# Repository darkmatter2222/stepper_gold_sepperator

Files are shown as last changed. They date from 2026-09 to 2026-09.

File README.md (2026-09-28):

# Stepper gold separator

PlatformIO / Arduino C++ firmware for the **ESP8266 NodeMCU ESP-12E shown in the hardware photo**, an assumed A4988 STEP/DIR carrier, one momentary button, and a switched 12 V Kamoer water pump. This is not an ESP32 build. It repeatedly rocks the bowl, pauses to settle, performs a ramped forward spin, pauses, and repeats until stopped.

**Starts stopped every time.** No unexpected motion after reset, firmware upload or power restoration. This firmware implements experimental motion, not proven gold recovery. The previous 64 mm bowl design does not establish an optimal speed. HIGH is a relative preset name, not a validated operating limit.

## Project files and revision selection

**For the current small prototype, use the v2 kit with the revised P01 cable-clearance base, P05 M3 hub and P08 brass-inlet lid.** Do not print the original P01/P05/P08 from the v2 snapshot for the current build. The original large v1 is preserved for reference.

| Folder or file | Contents / purpose |
|---|---|
| [Mechanical index](mechanical/README.md) | Current print list, quantities, revision precedence and archive map |
| [v2 kit](mechanical/gold_poc_v2/) | All nine original STL parts, individual STEP solids, assembly STEP, CAD generators, calculations, validation and rendered views |
| [Reinforced cable-clearance base](mechanical/base_cable_revision/) | Current P01 replacement; straight diagonal posts; existing P02 retained with four new drilled holes, wider posts and flared feet |
| [Hardware dimensions and assumptions](docs/HARDWARE.md) | Motor, pump, tubing, bearing, fastener and electronics reference; measured values separated from assumptions |
| [M3 drive hub](mechanical/hub_m3_revision/) | Current replacement P05, editable source, section and reviewed views |
| [Brass-inlet lid](mechanical/lid_water/) | Current replacement P08, editable source, section and reviewed views |
| [Illustrated assembly PDF](docs/guides/Central_Trap_Gold_POC_v2_Assembly.pdf) | Existing 18-page build guide; apply the hub/lid updates listed below |
| [Guide index and amendments](docs/guides/README.md) | Which guide applies and what has changed since its publication |
| [Original v1](mechanical/archive/gold_poc_v1/) | Superseded 128 mm bowl design and its source/checks |
| [Original ZIP deliveries](releases/original_packages/) | Unmodified v1 kit, v2 kit and M3 hub delivery packages |
| [Artifact manifest](docs/ARTIFACT_MANIFEST.json) | Byte sizes and SHA-256 checksums of preserved CAD, guides, source and review artifacts |
| [Wiring](docs/WIRING.md) / [pump](docs/PUMP.md) | Electrical connections, switching components and flow calibration |
| [Operating guide](docs/OPERATION.md) | Fill targets, staged feeding, size classification, capacity calculations and recovery tests |
| [Sources](docs/SOURCES.md) / [validation](docs/VALIDATION.md) | Research references, assumptions, checks and remaining physical tests |
| `src/`, `include/`, `test/`, `platformio.ini` | C++ firmware, settings, host tests and pinned PlatformIO environments |

The original assembly STEP and PDF show the original v2 base, hub and lid. The current replacement STEP files use assembly coordinates and can replace those parts in CAD. There is not yet a regenerated combined assembly STEP/PDF showing all three replacements. Their illustrated instructions take precedence for P01, P05 and P08.

## Mechanical design and hardware

This proof of concept has a **64 mm bowl**, reduced from the first version's 128 mm bowl. The original v2 assembled envelope is approximately **86 × 103 × 104 mm**, including the drain. The revised lid adds its collar above that height: its top is at assembly Z=120 mm, with a suggested 35 mm brass tube reaching approximately Z=137 mm, excluding flexible hose. Do not scale the STLs; motor, shaft, bearings and fasteners retain their real dimensions.

| Item | Current specification / qualification |
|---|---|
| Motor | Moons C17HD40-102-01N as reported; 5 mm shaft with a D-flat. Exact phase-current rating remains unverified |
| Motor envelope used in CAD | 42 mm square × 40 mm body, 31 mm mounting square, 22 mm pilot, shaft projection assumed about 18–26 mm |
| Shaft support | Separate 5 × 10 × 4 mm thrust bearing; motor supplies radial support |
| General assembly | M4 screws and heat-set inserts; v2 insert assumption approximately 6 mm OD × 6 mm long, nominal 5.6 mm pilot |
| Motor mounting | M3 threads in the motor; use the PDF's fastener schedule and confirm actual engagement |
| Revised P05 hub | One approximately 4.5 mm OD × 4 mm long M3 insert and M3 × 10 mm retaining screw against shaft flat; existing three M4 × 8 mm bowl attachments |
| Revised P08 lid | One matching-size M3 insert and M3 × 8 mm tube-retaining screw; original four M4 lid mounts retained |
| Brass inlet | 4 mm OD / 3 mm ID; start with 35 mm cut length; deburr both ends |
| Tube support | 4.2 mm socket, 18 mm engagement, 3.2 mm outlet below a positive seating shoulder |
| Feed opening | 26 mm diameter, retained in the revised lid |
| Pump | Kamoer NKP-DC-S10B, label 12 V / 5 W; actual flow and startup current require measurement |

Print the P09 insert coupon first. The nominal M4 insert hole is not universal; match it to your actual inserts. The M3 revisions also depend on insert OD and length, not just the M3 thread designation. PETG and robust perimeters are the starting print recommendations. Follow each part's orientation and support instructions. Closed STL geometry does not guarantee a watertight print; test wet parts separately.

The bowl has a blind central sump and smooth entrance; P07 is an optional recessed insert. The catcher uses a sloped floor and flush drain invert. A raised central shaft opening and splash labyrinth reduce splashing but are not a submerged rotary seal. Keep the drain open and capture all discharge. The inlet is off center, 22 mm from the axis, so it does not inject directly into the concentrate sump.

## Brass-tube lid and water pump

Print the [replacement lid STL](mechanical/lid_water/P08_lid_brass_4mm.stl), then follow the [illustrated assembly guide](mechanical/lid_water/README.md) and [12 V pump guide](docs/PUMP.md). The supported 4 mm brass tube seats on a shoulder so it cannot fall into the bowl.

## Wire first

See **[the wiring guide](docs/WIRING.md)** and **[the wiring diagram](docs/wiring.svg)**. The red carrier resembles an A4988, but its chip is hidden by the heatsink. Verify the driver model and printed terminal labels before powering it. A DRV8825 or another carrier may have different power pins and microstep settings.

Logical wiring diagram

| Signal | NodeMCU label | GPIO | A4988 / connection |
|---|---|---:|---|
| Step | D5 | 14 | STEP |
| Direction | D6 | 12 | DIR |
| Enable | D7 | 13 | EN, plus external 10k pull-up to 3V3 |
| Button | D2 | 4 | Normally-open button to GND |
| Water pump | D1 | 5 | 4.7k to 2N3904 base → IRF9540N high-side switch; see pump guide |
| Logic supply | 3V3 | | VDD, MS1, MS2, MS3, RESET, SLEEP |
| Common reference | GND | | Driver logic GND and motor-supply negative |

Use one regulated **12 V DC supply**: a secure branch feeds driver VMOT and the pump, while an **L7805 TO-220 linear regulator** supplies **5 V to NodeMCU VIN**. The upper breadboard positive rail is 5 V; the lower positive rail is 12 V; both negative rails share GND. Keep motor/pump current off breadboard rails. **Verify the actual regulator marking/pinout and NodeMCU VIN first; never apply 12 V to VIN or 5 V to 3V3.** See the wiring guide for capacitors, heatsinking and staged voltage checks. Disconnect external VIN power before attaching USB. The OLED partly visible in the photo is not required or driven by this firmware; disconnect it for initial testing, especially if it uses D2.

## Build and upload in VS Code

1. Install the PlatformIO IDE extension and open this repository folder (the one containing `platformio.ini`).
2. Turn off 12 V and disconnect the external 5 V-to-VIN lead before attaching USB. Select `nodemcuv2`, then click **Build**, followed by **Upload**. Keep external VIN disconnected while using USB Serial Monitor; unplug USB before restoring regulator power.
3. Open **Serial Monitor**, 115200 baud. If autodetection picks the wrong port, add `upload_port = COM5` and `monitor_port = COM5` with your actual Windows port.
4. It boots in LOW, IDLE. With wiring/current limit checked, hold the button for 0.8 seconds to start.

CLI equivalents:

```sh
pio run -e nodemcuv2
pio run -e nodemcuv2 -t upload
pio device monitor -b 115200
pio test -e native
```

The board/framework choice matches your [ESP8266 seismometer configuration](https://github.com/darkmatter2222/ESP8266_MPU6050_Seismometer/blob/main/platformio.ini). No GitLab account or URL was supplied; the accessible GitHub project was used. The platform and AccelStepper dependency are pinned for repeatable builds.

## One-button operation

| Action | Result |
|---|---|
| Short press and release | 1 → 2 → 3 → 4 → 5 → 6 → 1 |
| Hold for 0.8 seconds while idle | Start selected preset |
| Hold for 0.8 seconds while running | Decelerate to stop, then disable motor coils |
| Hold button during boot | No start; release it before normal operation |

While running, a newly selected mode is **queued until the next complete rock/settle/spin/rest batch**. It never changes speed abruptly mid-motion. The onboard LED flashes 1–6 times per three seconds for the selected mode. Serial reports the selected and currently active mode separately at the next motion pause. The LED pattern indicates mode, not running status.

Serial commands: `1`–`6` select; `s` start; `x` controlled stop; `!` immediately disables the driver; `?` requests status. `p` primes water for 3 seconds while idle; `c` runs a 30-second calibration while idle; `w` toggles automatic water. No newline required. Immediate disable removes holding torque and the bowl can coast. The button is a software control, not a physical emergency disconnect.

## Six modes and doubled agitation (2026-09-27)

The operator reports the previous mode 3 gave the best visible concentration and mud removal, with some heavy-mineral loss. Modes 1–3 retain their speeds and angles; their rocking cycle counts are doubled. Modes 4–6 are progressively faster trials, with counts chosen to preserve about 10 seconds of agitation. This increases time spent agitating; it does not double frequency.

| Mode | Name | Angle | Rock speed ceiling °/s | Rock accel °/s² | Cycles | Simulated agitation | Spin RPM | Spin accel °/s² |
|---|---|---:|---:|---:|---:|---:|---:|---:|
| 1 | LOW | ±12° | 540 | 7200 | 36 | 7.87 s | 90 | 1800 |
| 2 | MEDIUM | ±16° | 810 | 14400 | 48 | 8.62 s | 135 | 2700 |
| 3 | HIGH | ±20° | 1080 | 21600 | 60 | 9.92 s | 180 | 3600 |
| 4 | TRIAL4 | ±20° | 1170 | 25350 | 65 | 9.93 s | 195 | 3900 |
| 5 | TRIAL5 | ±20° | 1260 | 29400 | 70 | 9.93 s | 210 | 4200 |
| 6 | TRIAL6 | ±20° | 1350 | 33750 | 75 | 9.92 s | 225 | 4500 |

All modes retain 3 seconds settling, 0.5 seconds requested spin plateau and 2 seconds post-spin rest. Rocking brakes to zero before reversing, with triangular velocity profiles. Simulated frequencies are 4.60/5.59/6.07/6.57/7.07/7.58 Hz. Times are real-library host simulation results, not measured motor motion. Doubling cycle count approximately doubles duration; the initial/final half strokes prevent an exact 2.000× ratio.

Mode 3 is the comparison baseline. Try its longer agitation before increasing spin; modes 4–6 are not established recovery improvements. Keep all tailings. At 225 RPM the calculated radial acceleration at the 29 mm working radius is 1.64 g; faster ejection can lose desired minerals as well as gangue.

Keep existing 200-full-step, 1/16 microstep wiring. The maximum requested rate is now 12000 pulses/s, the existing software budget (about 83 microseconds per pulse). Actual ESP8266 scheduling/loaded torque are unmeasured. If motion stalls, slips or buzzes, stop and verify tracking rather than assuming commanded speed is achieved.

**Feeding and fill:** [OPERATION.md](docs/OPERATION.md) explains the photo, particle-size effects and staged feeding. The central void is about 2.27 mL up to its slope entrance, but that is not usable concentrate capacity. Start cleanup trials at roughly 0.5 mL retained settled bed; explore up to 1 mL only with acceptable measured losses. No validated maximum fill exists at mode 3 or the faster modes. Do not add unmeasured scoops to a full pocket. The machine supports periodic concentrate cleanup, not indefinite accumulation.

At the end of each spin, the stopped location becomes the next local rocking center. There is no homing sensor and no need to return to the original absolute shaft angle. Coordinates reset only at rest to avoid position accumulation over hours. No random stages are enabled, so experiments can be repeated and compared.

## Water delivery, flow rates and calibration

The pump runs at **full regulated 12 V when ON**. Firmware uses slow timed bursts rather than high-frequency PWM. GPIO D1 controls the MOSFET, not pump power directly. Automatic water defaults to enabled after boot, but output remains OFF until rocking begins. There is no unexpected prime on startup.

| Preset | ON per interval | OFF per interval | Nominal duty within a long uninterrupted rocking window | Ideal average if continuous flow is Q mL/min |
|---|---:|---:|---:|---:|
| LOW | 0.50 s | 4.50 s | 10% | 0.10 × Q |
| MEDIUM | 0.75 s | 4.25 s | 15% | 0.15 × Q |
| HIGH / TRIAL4 / TRIAL5 / TRIAL6 | 1.00 s | 4.00 s | 20% | 0.20 × Q |

**These are timing ratios, not measured water flow rates.** Each rocking batch begins with an ON pulse; the batch can end partway through an interval. Water is OFF during centering, settling, spin, rest and stopping. Consequently, multiplying by 10/15/20% does not give the whole-machine average, and the actual cyclic average is not necessarily lower than those ratios because intervals restart. Short-burst startup, pump rollers, hose elasticity, lift and outlet restriction also affect delivery. The exact NKP-S10B tube configuration and a manufacturer flow curve for this unit have not been verified. We have not simulated or optimized this system's water flow.

For measured pump ON time `t_on` over complete elapsed time `T`, an ideal estimate is `Q_cycle ≈ Q_continuous × t_on / T`. Measuring actual collected volume over complete cycles is better.

1. Route the installed outlet to a graduated cup at the operating height. Prime the line with `p` (3 seconds) until it is full and bubble-free.
2. While idle, send `c` for a 30-second continuous pump run. If the cup contains **V mL**, the measured continuous estimate is **2 × V mL/min**. Repeat for consistency.
3. Run each preset for a measured number of minutes, collecting output across complete motion batches. **Actual average mL/min = collected mL ÷ elapsed minutes**. Record tube dimensions, lift, preset and edited timings with the result.
4. Confirm the assembled catcher's outlet clears inflow without a rising level. Start with an empty bowl, then water, then a very small prepared sample. No maximum drain throughput has been measured.
5. Edit `PUMP_SCHEDULE` and repeat if the bed dries out, material cannot wash away or the catcher accumulates water. More water can also carry fine gold away. Retain tailings.

For arithmetic illustration only, collecting 20 mL during a 30-second calibration means 40 mL/min continuous. The ideal long-window rates at 10/15/20% duty would be 4/6/8 mL/min, but these are **not this pump's measured ratings** and must not be used as actual separator setpoints.

| Measurement | Current status |
|---|---|
| Nameplate supply | 12 V DC |
| Nameplate power | 5 W |
| Current inferred from 5 W / 12 V | About 0.42 A; not measured running or stall current |
| Continuous installed flow | Not measured |
| All six modes: whole-cycle flow | Not measured |
| Maximum catcher drainage rate | Not measured |
| Recovery versus flow or feed size | Not measured |

The brass bore has cross-sectional area about 7.07 mm². If actual flow is `Q` mL/min, mean velocity in its 3 mm ID straight section is approximately `0.00236 × Q` m/s. This dimensional calculation is not a nozzle, pressure-drop, splash or particle-recovery simulation. Flow near the bowl depends on the free jet and liquid bed as well as the tube.

Use the [pump guide](docs/PUMP.md) for MOSFET wiring, flyback protection, supply sizing, terminal direction and siphon checks. Keep hoses strain-relieved. A stopped peristaltic pump is not assumed to be a certified shutoff valve.

## Complete controls and settings

| Serial command | Meaning |
|---|---|
| `1`–`6` | Select one of six presets; apply at next complete batch if already running |
| `s` | Start motion from idle; automatic water follows its phase schedule |
| `x` | Shut water off immediately, decelerate motor, disable coils once stopped |
| `!` | Shut water off and disable drive immediately; rotor can coast |
| `p` | 3-second prime while idle only |
| `c` | 30-second calibration while idle only |
| `w` | Toggle automatic-water enable; cancel current pump output |
| `?` | Print phase, selected/active mode and water state |

Manual prime/calibration requests during motion are ignored. Repeating a manual command does not extend an active dose. Starting motion cancels manual dispensing. A short button press changes the selected preset; it is not a stop command. A long press starts or requests controlled stop. Use a physical power disconnect when servicing.

`include/Config.h` contains motion profiles, pin numbers, motor steps, microstep count, pump ON/OFF times, prime/calibration duration, direction inversion and the experimental `PUMP_DURING_SPIN` option (default false). Durations are milliseconds unless the field says otherwise. All settings are compile-time; rebuild and upload after editing. Serial changes are not persisted after reset.

## Separation mechanics and research limits

The intended sequence is rocking to loosen/stratify the bed, a quiet settling interval, then a brief ramped forward spin to move some material outward. Gravity and the bowl slope can favor inward transport when grains can move. Rotation produces outward acceleration `a = omega² × radius`; it is not a guarantee that light material exits while all gold stays centered. Both grain size and density matter, and flakes can behave differently from spheres.

At the 29 mm working radius, 90/135/180/195/210/225 RPM correspond to approximately 0.263/0.591/1.050/1.233/1.430/1.641 g radial acceleration. These are analytical screening values, not a recovery model. See [capacity calculations](docs/CAPACITY_SCREENING.json) and [motion history](docs/MOTION.md).

The goal is a dense concentrate at the center. The pocket can fill with black sand and other heavies; it cannot guarantee pure gold or prevent every fine particle escaping. Clay must be dispersed to free trapped gold; wet screening alone may not do that. The present prototype has no automated feed conveyor or concentrate discharge. Automatic repeated motion is implemented; hours of unattended bucket-scale processing have not been established.

## Tuning and first run

Edit `include/Config.h` for pins, motor step count, microstep count, direction inversion and presets. Settings are compile-time and are not written repeatedly to flash. No Wi-Fi, cloud service or phone is needed. Water bursts are integrated into the rocking phase; see [pump wiring and calibration](docs/PUMP.md).

1. Verify motor coil pairs, driver identity, supply polarity and current limit as described in the wiring guide. The exact Moons motor's phase-current rating is not known from the photo.
2. Hand-turn the assembled bowl and check the new M3 hub screw and bearing clearance. Secure the cover and catch all overflow.
3. Start LOW with an empty bowl, then water only. Stop if it stalls, buzzes without moving, rubs, or gets excessively hot. Confirm direction; `INVERT_DIRECTION` reverses it.
4. Add a very small screened/dispersed sample. Keep all tailings and measure losses before increasing intensity. Start with measured small doses and the fill/cleanup procedure in OPERATION.md. Faster modes can increase losses.
5. Tune one parameter at a time. More spin pushes particles outward and can remove gold as well as sand. Clay, flakes and bed loading affect settling; these dwell times are not a guarantee that flour gold settles.

No encoder, stall detection, current measurement, temperature sensor or blocked-drain detection is provided by this hardware/software. A4988 does not report these conditions to this controller. Long unattended processing is not validated. The loop uses AccelStepper cooperatively with Wi-Fi disabled; verify actual timing under your hardware conditions before increasing pulse rates. Logging is deferred when the serial transmit buffer lacks space.

## Validation

Host tests cover boot-idle behavior, button bounce/long-press/boot-held behavior, millisecond rollover, queued mode transitions, every normal stop phase, immediate disable, spin-distance calculation, and coordinate resets over 1000 batches. The fake motor tests control logic; they do not establish physical pulse timing or recovery. GitHub Actions runs those tests and builds the ESP8266 firmware. See [sources and engineering notes](docs/SOURCES.md).

Pump tests cover burst timing across reversals, phase gating, preset timing, immediate cancellation, manual time limits, rollover and delayed-loop behavior. The original pump revision passed 15 host tests and built for `nodemcuv2` (RAM 28,844 bytes; flash 273,491 bytes). See [validation](docs/VALIDATION.md) for the current motion revision. Hardware flow and electrical startup behavior remain to be measured.

## P01 straight-post correction

The rejected angled-post version has been replaced with [straight vertical posts](mechanical/base_cable_revision/README.md), rotated to the diagonal positions. Posts are 12 mm nominal diameter with 16 mm flared feet. Unused bottom holes and cable-tie slots are removed. **Keep the existing P02 upper plate, but drill four new 4.5 mm holes using the included template.** No upper-plate reprint is needed; this is not a fit against the unchanged old hole pattern. Local reliefs clear the motor corners and existing upper bosses. See the revision instructions before printing or drilling.

The source, STL/STEP, template, drilled-deck reference STEP, assembly views and checks are committed together. Hardware dimensions and unresolved measurements are in [HARDWARE.md](docs/HARDWARE.md). Pump body dimensions remain unmeasured; no flow or physical strength guarantee is implied.

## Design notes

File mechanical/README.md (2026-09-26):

# Mechanical files and current print list

Use the compact **v2** kit with **all three** revisions below. The original snapshots and ZIPs are retained without rewriting their contents.

| Part | Qty | Current print file |
|---|---:|---|
| P01 base | 1 | [STL](base_cable_revision/P01_BASE_STRAIGHT_VERTICAL_R3.stl) |
| P02 motor deck | 1 | [STL](gold_poc_v2/STL/P02_motor_deck.stl) |
| P03 spacer | 4 | [STL](gold_poc_v2/STL/P03_spacer_x4.stl) |
| P04 catcher | 1 | [STL](gold_poc_v2/STL/P04_catcher.stl) |
| P05 drive hub, M3 revision | 1 | [STL](hub_m3_revision/P05_drive_hub_M3.stl) |
| P06 bowl | 1 | [STL](gold_poc_v2/STL/P06_bowl.stl) |
| P07 optional trap insert | 0 or 1 | [STL](gold_poc_v2/STL/P07_optional_trap_insert.stl) |
| P08 brass-inlet lid | 1 | [STL](lid_water/P08_lid_brass_4mm.stl) |
| P09 insert coupon | 1 initially | [STL](gold_poc_v2/STL/P09_insert_coupon.stl) |

All dimensions are millimeters. Do not scale. STEP files and editable Python generators accompany each revision. Hardware STEP envelopes in the kit are reference solids, not printable substitutes for motors/bearings.

Read the [assembly guide index](../docs/guides/README.md), [M3 hub instructions](hub_m3_revision/README.md) and [brass lid instructions](lid_water/README.md). The baseline kit's PDF and assembly STEP predate those three replacements. Its original base, hub and lid remain available only as revision history.

## Folder organization

- `gold_poc_v2/`: complete compact kit, original PDF, source, model files, review images and calculation/check records. The original relative layout is retained so source and assets remain together.
- `hub_m3_revision/`: current P05 and its validation/rendering source. Kept beside `gold_poc_v2` so original clearance-reference paths work.
- `lid_water/`: current P08 and its validation/rendering source. Pass `../gold_poc_v2/STEP` to the generator when running from this folder to include original-kit clearance checks.
- `archive/gold_poc_v1/`: superseded larger prototype. Do not mix its parts with v2.
- `../releases/original_packages/`: unmodified historical delivery ZIPs.

The files are preserved deliverables, not newly manufactured/tested hardware. Geometry checks describe the revision that generated them. Re-run appropriate checks after any edit. The v2 guide generator writes its PDF to its parent folder; avoid overwriting the preserved guide inadvertently.

The large intermediate mesh-render cache is preserved losslessly as `gold_poc_v2/assets/meshes.json.gz`. Run `gzip -dk assets/meshes.json.gz` from the v2 folder if a rendering script needs the JSON cache; the original generators can also recreate it.

## Straight-post base correction

Use [base_cable_revision](base_cable_revision/README.md) for P01. All post axes are vertical, at the diagonal positions. The printed P02 deck is retained but needs four new 4.5 mm holes using the supplied drill template. The previous angled supports are rejected and superseded. Bottom cable-tie/anchor holes have been removed. Read the complete instructions before printing.

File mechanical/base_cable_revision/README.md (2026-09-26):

# P01 straight-post base: corrected revision

**Download `P01_BASE_STRAIGHT_VERTICAL_R3.stl`.** Remove the previous angled model from your slicer before importing this file. Its posts run vertically, with no sideways displacement between their top and bottom axes. The earlier reused filename could make downloads difficult to distinguish.

[Base STL](P01_BASE_STRAIGHT_VERTICAL_R3.stl) · [Base STEP](P01_BASE_STRAIGHT_VERTICAL_R3.step) · [Drill-template STL](P02_drill_template.stl)

**This replaces the rejected angled/swirl-post design. All four post axes are now straight and vertical.** The lower and upper ends occupy the same diagonal positions, 45° from the original post layout. The base has no unused anchor holes or cable-tie slots.

**Keep your printed P02 upper plate, but drill four new 4.5 mm clearance holes in it.** The old upper screw holes are at the cardinal positions. They cannot fasten straight diagonal posts. This is not a drop-in replacement against an unmodified P02. If you do not want to drill it, do not print this revision on the assumption that its holes already match.

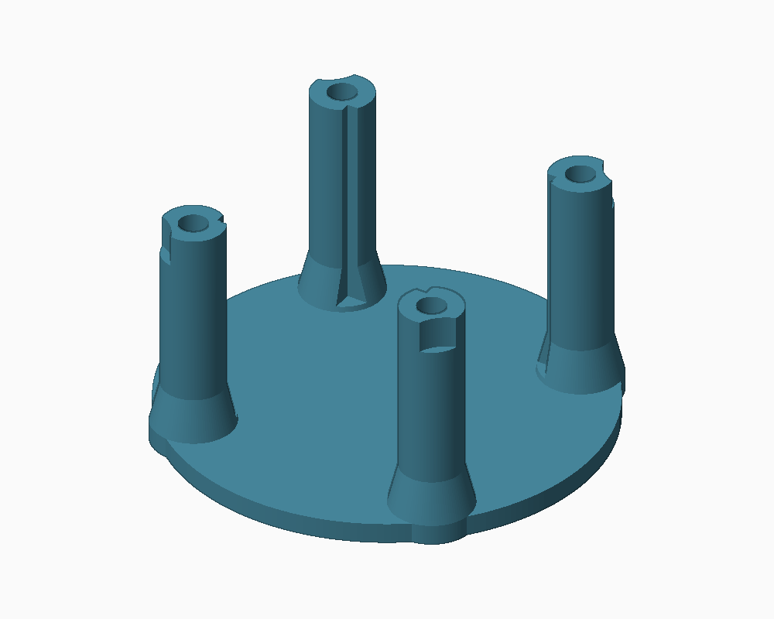
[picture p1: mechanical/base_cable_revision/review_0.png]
Straight-post base


## Dimensions and changes

| Feature | Corrected geometry |
|---|---|
| Main plate | 84 mm diameter, 4 mm thick |
| Post axes | Radius 35.5 mm, angles 45/135/225/315°; vertical throughout |
| Post section | 12 mm nominal diameter; original posts were 9 mm |
| Feet | 16 mm nominal diameter, taper to 12 mm over Z=4–12 |
| Top height | Z=46 mm, same height as original base |
| M4 insert pilot | 5.6 mm diameter, 6.5 mm depth |
| New upper plate holes | 4.5 mm diameter at X/Y = ±25.1023 mm (all four combinations) |
| Motor clearance | 44 × 44 mm internal relief around assumed 42 × 42 mm motor |
| Existing deck bosses | Local curved relief at post tops, radius 7.3 mm about the original R47 boss centers |
| Extra bottom holes | Removed |

The inward post/foot faces are locally relieved to clear the motor corners. A small curved relief at each post top clears the existing upper plate's underside mounting boss. These are clearance cuts in straight vertical posts, not angled arms. Feet have rounded plan outlines; no supports should be required for the base in its supplied flat orientation, but inspect your slicer preview.

## What the old holes were

The original P01 had two rectangular 3 × 7 mm slots for cable ties/strain relief. No printed part was intended to fit them. Its four round bottom holes were optional base anchoring holes, not required separator assembly interfaces. Both sets are removed from this corrected base. The required M4 insert pockets remain at the post tops.

## Print and fit

1. Print the base flat at 100% in millimeters. PETG, approximately 0.2 mm layers and at least five perimeters are starting settings. Review infill and layer bonding around the feet. No physical strength test has been performed.
2. Fit four M4 heat-set inserts, assuming approximately 6 mm OD × 6 mm long, after checking your actual inserts against the original coupon. Let them cool; inspect the locally relieved post tops for damage.
3. Disconnect power and remove the motor and upper components from P02 before drilling. Keep debris out of bearings, motor and electronics.
4. Print the 3 mm thick drill template. Its four cardinal holes at radius 36 mm align with the old base screw holes. Locate it on the **top face** of P02 using two opposite old holes and temporary M4 screws; clamp the plate flat on scrap wood. The template's center opening clears the central pedestal. Do not confuse its locating holes with the four new diagonal holes.
5. Mark the four new diagonal centers through the template. Remove the template, check spacing (50.2046 mm square), then drill 4.5 mm through P02's 4 mm plate only. Deburr. The template is a positioning aid, not a hardened drill bushing; do not melt it with a powered bit. Existing outer bosses/catcher holes must remain untouched.
6. Reassemble using the original four M4 × 10 mm deck-to-base screws in the **new** holes. Confirm insert engagement and that the screws do not bottom out. The four old deck clearance holes are now unused; leaving them open does not change the dry deck's function.
7. Connect the harness through the open face between posts and confirm plug/latch access and cable bend clearance. Hand-turn the rotor, then test empty at LOW. Firmware is unchanged.

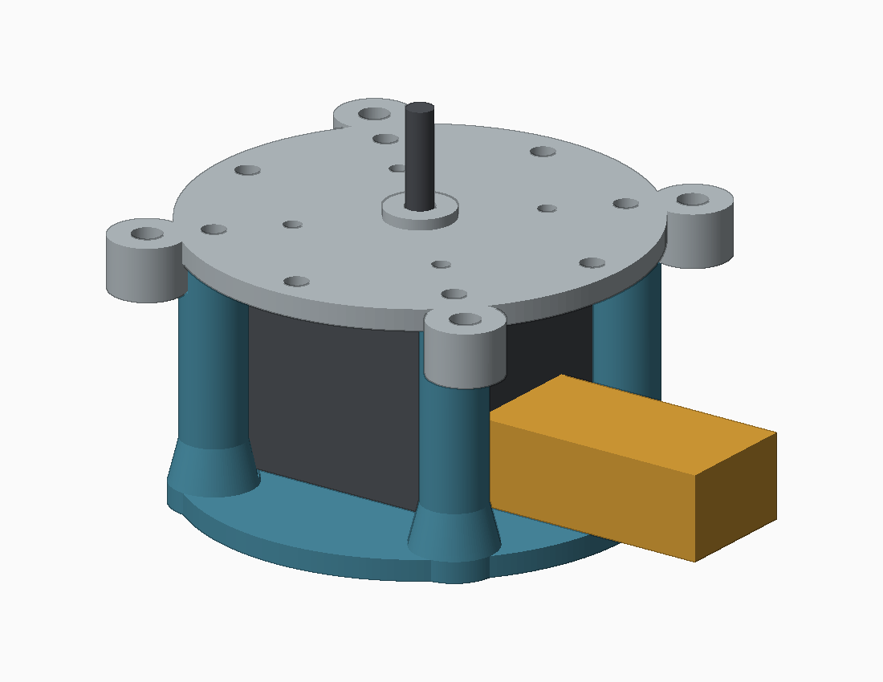
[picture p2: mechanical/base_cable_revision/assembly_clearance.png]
Base with motor, drilled deck and connector allowance


## Checks and reference files

CAD checks verify one valid base solid, closed/oriented STL, and no volumetric intersection with the motor envelope, drilled deck or 24 mm-wide × 16 mm-high assumed connector corridors (Z=6–22) on any of four faces. Connector dimensions remain unmeasured. Review images show the actual exported STL. `checks.json` records results.

`P02_drilled_reference.step` shows the **existing plate with four new holes**, for inspection, not a request to reprint it. `base_motor_deck_reference.step` includes the corrected base, reference motor and drilled deck. `P02_drill_template.step` is editable template geometry. The main kit's original PDF and assembly STEP remain historical snapshots; these instructions supersede their base attachment step.

Run `python build_base.py` with CadQuery 2.7, NumPy, SciPy and Pillow to regenerate. Original references come from `../gold_poc_v2/STEP`. Print tolerances, actual cable fit and structural performance require physical verification.

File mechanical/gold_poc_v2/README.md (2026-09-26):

# Central Trap v2 - compact experimental gold separator

Start with `Central_Trap_Gold_POC_v2_Assembly.pdf`. It contains the 18-page illustrated build sequence, hardware list, fit checks, printing notes, water-path sections, commissioning plan and research limitations.

## Size and changes

- Bowl diameter: 64 mm (v1: 128 mm).
- Assembled envelope: approximately 86 x 103 x 104 mm, including drain.
- Motor, M4 fasteners, inserts and bearing remain full-size. Do not halve these STLs in the slicer.
- One-piece wet bowl with smooth central sump entrance and blind dry mounting holes.
- Catcher floor slopes 3% to a flat-bottomed drain bore. Its invert follows the floor; no raised drain sill is designed in.
- Rounded mounting bosses replace square tabs. Recessed center insert is optional and gravity-seated, not a one-way trap.
- Direct 5 mm motor-shaft drive with a separate 5 x 10 x 4 mm thrust bearing. The motor still provides radial support.

## Before printing

The exact Moons C17HD40-102-0 1N specification was not verified. Check the assumptions: 42 mm square, 40 mm body, 31 mm mounting square, 22 mm pilot no more than 2 mm high, 5 mm shaft with approximately 18-26 mm projection from the motor mounting face. A longer body, different pilot or different shaft projection needs a CAD revision.

Print P09 first. Nominal insert bores are 5.6 mm, intended for roughly 6 mm OD x 6 mm long M4 inserts. Your insert manufacturer's bore recommendation takes precedence. The coupon contains 5.2, 5.4, 5.6, 5.8 and 6.0 mm bores. M3 screws are required only for the motor's own mounting threads; assembly hardware is M4.

Print one of each STL except P03 (four copies). P07 is optional. STLs are already print-oriented. P02 needs support around the bearing pedestal; P04 needs support under its spout/body and projecting upper bosses; P06 needs external support under the flare and skirt. Keep supports out of the wet working surface. Details are in the PDF.

## Package contents

- `STL/`: nine separate print files, millimeters.
- `STEP/`: individual solids in assembly coordinates plus simplified hardware reference geometry. Hardware models are not printable replacements for bearings or motors.
- `assembly.step`: assembled layout without screws, inserts, tubes or optional trap insert.
- `assets/review_*.png`: actual STL meshes, three viewpoints per part.
- `assets/section_*.png`: CAD sections through bowl and catcher.
- `assets/step_*.png`: exploded assembly illustrations.
- `geometry_checks.json`: solid validity, dimensions and interference checks.
- `mesh_checks.json`: STL closed-edge/orientation/positive-volume results.
- `mechanics_screening.json`: simple analytical calculations, not CFD.
- Python source for geometry, rendering, checks and the PDF.

## Verification and limits

All nine meshes were visually reviewed from three directions. CAD solids are valid; STL edges form closed oriented meshes with positive volume. Modeled printed parts, motor and bearing envelopes have no detected intersections. Rotor clearance was checked at 15-degree intervals. Fasteners are specified but not included in the interference model. Physical balance, torque margin, stepper temperature, print tolerances and water leakage are not validated by CAD.

There is NO CFD, multiphase particle simulation or measured gold recovery. The 20.2-degree slope is an experimental choice, not an optimized or proven geometry. Static friction, grain shape, mud rheology, surface roughness, gold size and water flow can defeat inward transport. Clay must be dispersed; screening alone does not free clay-bound gold. A deep pocket can fill with non-gold heavies. No guaranteed capture or unattended continuous-feed capability is claimed.

Mesh watertightness means closed geometry, not a leakproof FDM print. Leak-test wet parts separately. The catcher has an intentional raised central shaft opening and rotating splash labyrinth; it is not a submerged shaft seal. A blocked drain can wet the motor. The cover is a splash cover, not a pressure seal.

Start with water only, then very small screened samples. Retain and inspect all tailings. Follow the guide before trying spin/ejection pulses. To recover concentrate, stop and isolate power, remove the cover, use a small pipette/snuffer, and rinse the sump into a separate pan; remove the rotor for complete cleaning. Do not remove or collect from the rotating assembly.

## Rebuilding

Environment used: Python 3, CadQuery 2.7.0, NumPy 2.3.5, SciPy 1.17.0, Pillow 12.3.0, ReportLab 4.4.9. PDF generation also expects DejaVu Sans fonts in the standard Linux font path.

Run in order:

```bash
python build_v2.py
python checks_v2.py
python render_v2.py
python make_guide.py
```

Geometry dimensions are in `build_v2.py`; `INS` controls insert-bore diameter. Motor changes require checking the full stack and clearances rather than scaling the assembly. The PDF generator writes its PDF in the parent directory. Scripts overwrite generated artifacts; preserve a copy before modification.

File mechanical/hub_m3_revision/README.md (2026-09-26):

# P05 drive hub - single M3 insert revision

This part replaces only P05 in Central Trap v2 (64 mm bowl). All other printed parts remain unchanged. The previous guide's two M4 hub inserts and two opposed set screws are superseded by ONE M3 insert and ONE M3 screw.

## Hardware and pocket

- One M3 heat-set insert, assumed approximately 4.5 mm outside diameter x 4 mm long.
- One M3 x 10 mm socket-head screw with a flat end, bearing on the motor shaft's D-flat. A blunt flat-point grub screw may also be used if its length/reach is checked.
- Nominal insert pilot: 4.0 mm diameter, 4.5 mm pocket depth, 0.3 mm entry chamfer. Insert flush with the flat outside boss face. The final 3.2 mm passage leads to the shaft bore.
- M3 refers to the thread, not the insert's outside diameter. Verify your actual insert dimensions and recommended pilot before printing; do not force a larger insert into this pocket.

## What changed

A solid round radial boss supports the insert all the way around and provides a flat face for installation. The screw is lower than in the previous design so a straight hex key can reach it through the gap below the catcher. The second radial hole is gone.

Preserved interfaces: 36 mm flange, 10 mm total hub height, 5.1 mm motor-shaft bore, 29 mm bolt circle with three 4.5 mm holes, and the 10 mm diameter bearing nose. The shaft bore remains round to accommodate an unmeasured D-flat; the single screw presses the shaft against the opposite bore wall.

## Assembly

1. Print the STL in its supplied orientation, broad flange on the bed. Use the prior kit's PETG and perimeter settings. Keep the horizontal insert pocket clean; check the slicer for any local support needed and remove it completely.
2. Before attaching the bowl, heat-set the M3 insert from the outside of the boss. Align it with the hole and seat it flush. Let the part cool completely. Do not melt the insert through the pocket shoulder or distort the shaft bore.
3. Check that the screw threads smoothly through the insert and can reach into the shaft bore. Back it out to clear the bore.
4. Attach the hub to the bowl using the existing three M4 x 8 screws.
5. Lower the rotor onto the 5 mm shaft and thrust bearing as before. Align the shaft D-flat with the new M3 screw.
6. Tighten the M3 screw gently against the flat through the under-catcher access gap. Avoid bearing preload and excessive torque on the plastic insert boss.
7. Hand-turn the rotor through a full revolution. Check screw-head clearance, bearing freedom and any visible wobble before powering it.

The nominal M3 x 10 screw is modeled with its tip at a shaft flat 2 mm from the shaft center. Actual flat depth and screw end geometry vary. Confirm it clamps the shaft before any other surface bottoms out. A socket screw head may sit slightly proud of the boss; that is intentional and included in the clearance check.

## Included files and validation

- P05_drive_hub_M3.stl: millimeters, ready to slice; do not scale.
- P05_drive_hub_M3.step: original assembly coordinates, for CAD editing.
- build_hub.py: editable source. INSERT_BORE and INSERT_DEPTH control the pocket.
- review_0.png through review_3.png: views rendered from the actual exported STL.
- assembled_hub.png: illustration with nominal insert and screw envelopes.
- section.png: section showing the insert pocket and shaft passage.
- checks.json: mesh and clearance results.

The STL is checked for closed, consistently oriented edges and positive volume. CAD checks include the nominal screw head at 15-degree rotational increments against the existing catcher, deck and cover, plus a straight hex-key access envelope. These are geometry checks, not a physical print or clamp-strength test. One screw and insert introduce some imbalance; no high-speed balance or torque rating is claimed.

The source uses CadQuery, NumPy, SciPy, Pillow and the included render_support.py. Full assembly-clearance verification also uses the previous kit's STEP references. Keep this folder alongside the previous kit folder named gold_poc_v2 to re-run those checks. Without those reference files, only the hub and mesh checks run.

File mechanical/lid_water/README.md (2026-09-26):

# P08 replacement lid — 4 mm brass water inlet

[Print STL](P08_lid_brass_4mm.stl) · [Editable STEP](P08_lid_brass_4mm.step)

Only the lid changes. Original 86 mm body, 26 mm material-feed opening and four M4 mounting positions are retained. The old spare water hole is closed. The supported inlet is 22 mm off center; it does not aim directly into the central concentrate trap.

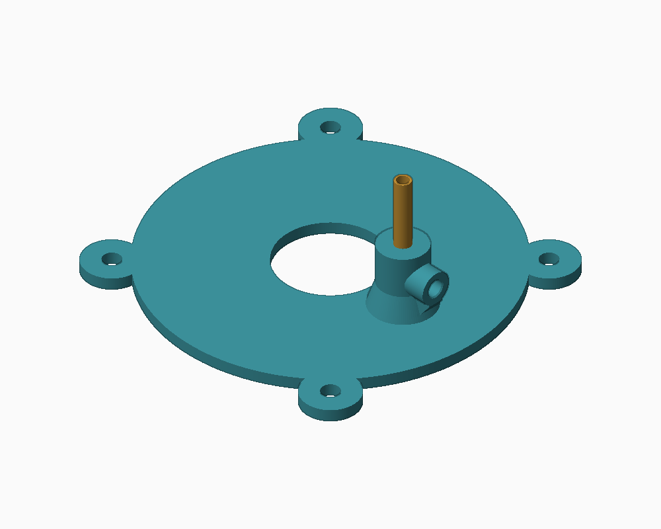
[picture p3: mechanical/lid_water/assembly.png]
Assembled lid


## 1. Print the lid

Print the STL as supplied, flat underside on the bed, without scaling. PETG, 0.2 mm layers and at least five perimeters are a practical starting point. Overall height is 19 mm. Inspect the horizontal insert bore for bridge sag; use localized support if your printer requires it. Remove burrs without thinning the water passage. Printed plastic is not automatically watertight: water-test before installing electronics underneath.

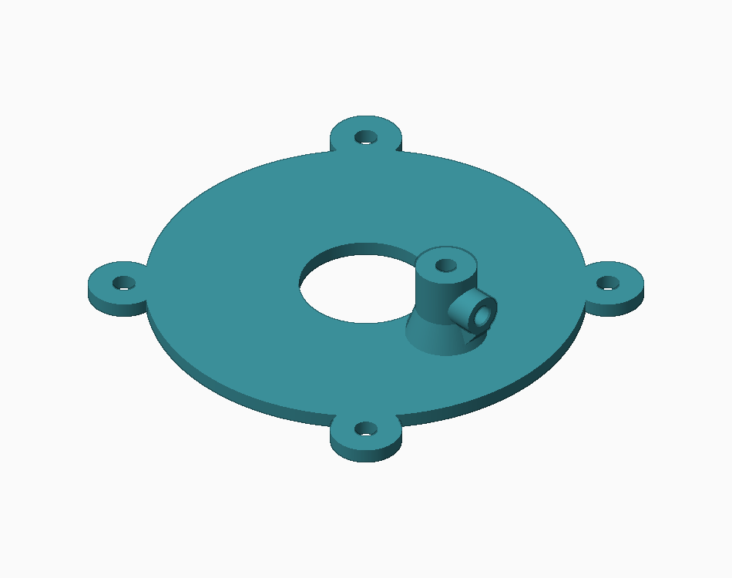
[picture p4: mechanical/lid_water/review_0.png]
Printed part


## 2. Fit the insert

The radial boss accepts **one M3 heat-set insert approximately 4.5 mm OD × 4 mm long**, using a nominal 4.0 mm pilot, 4.5 mm deep. Measure your inserts first; other sizes require changing `build_lid.py` and regenerating. Heat-set from the outside, square to the bore and flush with the boss. Do not push into the brass socket. Let cool before threading.

## 3. Seat the brass tube

Deburr a starting length of **35 mm**, 4 mm OD / 3 mm ID brass tube. Insert vertically until it seats: the 4.2 mm socket supports **18 mm** of tube, leaving about 17 mm above the collar for the flexible hose. A **3.2 mm water passage** below the shoulder lets water out while physically preventing the 4 mm tube from dropping through into the rotor. Do not drill the socket through the shoulder.

If necessary, carefully hand-fit the long socket to your actual tube. A small amount of fully cured, compatible silicone at the seat can seal seepage; keep the water passage clear. This is an open discharge, not a pressure-rated fitting.

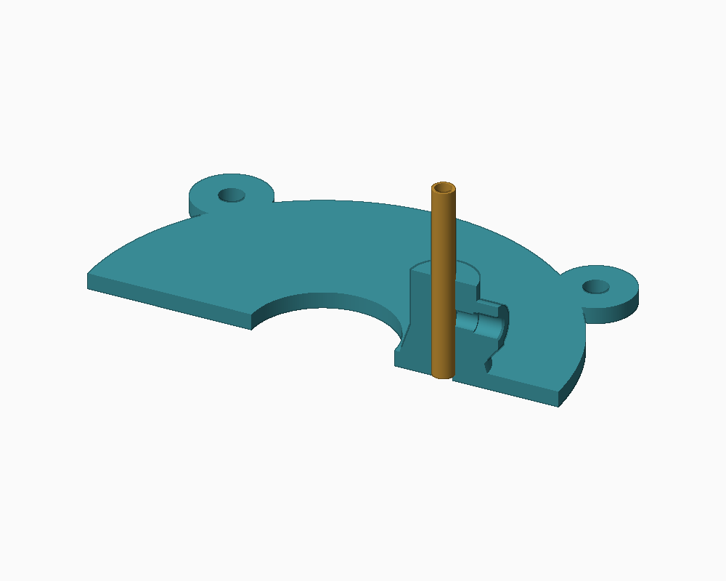
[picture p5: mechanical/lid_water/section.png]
Section through collar and brass tube


## 4. Retain and connect

Install **one M3 × 8 mm socket-head screw** into the insert and tighten only enough to retain the tube. Its 0.5 mm wall can be crushed. Slip compatible flexible pump outlet hose onto the exposed brass; confirm a secure fit with your actual hose ID and material. Support the hose separately so it cannot lever on the collar. The shoulder, not the screw, sets tube depth.

## 5. Replace the lid

Refit using the existing four M4 lid screws/inserts (original nominal M4 × 8 mm). Check actual screw engagement and clearances. Hand-turn the bowl with power disconnected, then test water only. No brass projects below the lid underside.

## Verification and regeneration

CAD is one valid solid; STL is closed and consistently oriented, 17,854 triangles. Lid, seated brass and nominal M3 screw have no intersections with the original P04 catcher or P06 bowl. Four mesh views and a section were visually reviewed. These are digital checks, not a verified physical print or pressure test. See [checks.json](checks.json).

Install Python dependencies `cadquery numpy scipy pillow` (generated with CadQuery 2.7). Run `python build_lid.py /path/to/original/STEP` to also check the original P04/P06 clearances, or omit that argument to regenerate the part alone. STEP uses original assembly coordinates; STL is translated for printing. The model does not change the bowl or establish separation efficiency.

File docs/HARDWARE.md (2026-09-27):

# Hardware identities, dimensions and assumptions

This is the reference for the actual hardware reported/shown and the dimensions used in CAD/firmware. **Reported/photo-confirmed values are distinguished from unmeasured design assumptions.** All mechanical dimensions are millimeters. A generic family drawing is not treated as a verified drawing of this exact hardware.

## Stepper motor

| Property | Value | Evidence / status |
|---|---|---|
| Brand/type | Moons stepping motor | User label transcription |
| Label transcription | C17HD40-102-0 1N | Original user wording; commonly recorded in this project as C17HD40-102-01N; exact datasheet not verified |
| Shaft diameter | 5 mm | User measured |
| Shaft flat | One D-flat | User described; depth/length not measured; not a keyway |
| Body width/depth | 42 × 42 mm | CAD assumption, conservative square envelope |
| Body length | 40 mm | CAD assumption |
| Mounting square | 31 × 31 mm | CAD assumption; four holes at X/Y ±15.5 |
| Motor mounting threads | M3 | Assumed NEMA-17 interface; check actual motor |
| Pilot boss | 22 mm diameter, at most 2 mm high | CAD assumption |
| Shaft projection above motor face | Approximately 18–26 mm usable range; reference solid uses 24 mm | CAD assumption; relief/stack checked for this range |
| Reference position | Body Z=6–46, motor face Z=46, shaft reference tip Z=70 | Assembly coordinates |
| Full steps per revolution | 200 (1.8°) | Firmware assumption, not confirmed from this motor's datasheet |
| Phase current, resistance, inductance, torque curve | Unknown | Do not infer from shaft size or frame size |
| Connector type, pin pitch, exact housing size | Unknown | New photos establish a side socket blocked by the original support; no scale measurement |
| Revised base connector allowance | 24 mm tangential width × 16 mm height, Z=6–22, radial path 21–66 | Explicit unmeasured clearance allowance tested on all four faces |
| Cable bend radius and mating plug protrusion | Unknown | Confirm with actual harness; straight clearance envelope does not characterize flexible cable routing |

Motor reference CAD: [`H_motor.step`](../mechanical/gold_poc_v2/STEP/H_motor.step). It does not contain the actual connector. The revised base generator adds a separate clearance envelope for that purpose. Motor coils must be identified by resistance pairing; colors are not a verified pinout.

## Peristaltic pump

| Property | Value | Evidence / status |
|---|---|---|
| Manufacturer/model | Kamoer NKP-DC-S10B | Read from supplied pump photograph |
| Supply | 12 V DC | Nameplate |
| Power | 5 W | Nameplate |
| Current from power/voltage arithmetic | Approximately 0.42 A | Estimate only; not measured running/startup/stall current |
| Head OD, motor/body length, total envelope | **Not measured / not assumed in CAD** | No pump mount/enclosure has been designed |
| Mounting-hole spacing/diameter | **Unknown** | Required before designing a pump bracket |
| Pump tubing ID/OD and free hose length | **Unknown** | Must measure the installed tubing; do not confuse it with the brass outlet bore |
| Rated/installed flow | **Not verified / not measured** | Use the 30-second calibration and complete-cycle collection procedure |
| Maximum pressure/suction lift, duty rating | **Not verified for this exact unit** | No value assumed in this design |
| Terminal polarity for desired pumping direction | Not established from photograph | Brief protected test; reverse motor leads with power off if necessary |

The Kamoer NKP family contains variants. No generic family dimensions or advertised flow range are substituted for measurements of this NKP-DC-S10B. Record actual length × width × height, fixing pattern, tube diameters, full-on mL/min, installed lift and startup current here when measured. Existing source links are in [SOURCES.md](SOURCES.md).

## Brass inlet, bearings and fasteners

| Interface | Dimensions | Status |
|---|---|---|
| Brass tube | 4 OD / 3 ID | User supplied measurements |
| Suggested tube cut length | 35 | Design starting length, not measured existing part |
| Lid tube socket | 4.2 diameter × 18 engagement | CAD dimension |
| Outlet below tube seat | 3.2 diameter; seat 1 mm above underside | CAD dimension; shoulder prevents tube dropping into bowl |
| Thrust bearing | 5 ID × 10 OD × 4 high | Selected design assumption; verify purchased bearing |
| General M4 inserts | About 6 OD × 6 long; 5.6 pilot | Original CAD assumption; fit coupon spans 5.2–6.0 pilots |
| Hub/lid M3 inserts | About 4.5 OD × 4 long; 4.0 pilot × 4.5 pocket | Revision CAD assumption; thread size alone does not specify insert envelope |
| Hub shaft hole | 5.1 diameter | CAD clearance for 5 mm shaft |
| Hub retaining screw | M3 × 10, blunt end on D-flat | Selected starting hardware; confirm reach against actual flat |
| Lid tube retaining screw | M3 × 8 | Selected starting hardware; tighten gently to avoid crushing tube |
| Bowl-to-hub attachment | Three M4 × 8, 29 mm bolt circle | Existing design |
| Lid attachment | Four M4 × 8 nominal, radius 47 at 45/135/225/315° | Existing design; verify engagement |
| Base-to-deck interface | Corrected base: four vertical axes at radius 35.5, diagonal angles; top Z=46; 5.6 × 6.5 insert holes | Requires four new 4.5 mm deck holes at X/Y ±25.1023; reuse original M4 × 10 screws after engagement check |

## Electronics

| Item | Identity / setting | Status |
|---|---|---|
| Controller | ESP8266 NodeMCU ESP-12E | Photo identified; earlier verbal ESP32 description was corrected |
| Board envelope and fixing holes | Unknown / no printed electronics enclosure | Must measure before creating mounts |
| Stepper driver | Assumed A4988 STEP/DIR carrier | Chip hidden by heatsink; verify before wiring |
| Driver carrier size / mounting pattern | Unknown / not used in CAD | Do not infer from PCB color |
| Microsteps | 1/16; MS1/MS2/MS3 high for verified A4988 | Firmware/hardware configuration assumption |
| Pump switch | IRF9540N high-side + 2N3904 driver | Part numbers visible on inventory boxes; actual maker/pinout must be verified |
| Protection | 1N5822 flyback; 4.7k base, 100k base-emitter, 10k gate-source, 1k gate-collector | Specified circuit |
| Capacitors | 100 nF across pump; 100 µF/25 V supply bulk for 12 V | Specified circuit; stepper VMOT also has its own bulk capacitor |
| Power | Shared regulated 12 V; L7805 TO-220 + heatsink converts to 5 V for NodeMCU VIN; driver logic remains 3.3 V | Supply current capacity and current limit require hardware confirmation |

See [WIRING.md](WIRING.md), [PUMP.md](PUMP.md) and `include/Config.h` for exact nets and firmware settings. No undocumented connector dimensions, motor current rating or pump flow are assumed to be measured facts.

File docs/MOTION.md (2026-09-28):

# Current revision: six modes and longer agitation

The current preset table is in [README](../README.md#six-modes-and-doubled-agitation-2026-09-27). Modes 1–3 preserve 90/135/180 RPM and double rocking counts to 36/48/60. New modes 4–6 run at 195/210/225 RPM with 65/70/75 cycles, retaining about 10 seconds agitation. Rocking angles stay at ±20 degrees for modes 3–6. Settling, spin plateau and rest remain unchanged. Button/serial/LED selection now covers six modes; new pump profiles reuse HIGH's intervals. Existing 12000 pulses/s budget is retained. Real board pulse timing and loaded torque remain unmeasured.

Read [OPERATION.md](OPERATION.md) for the new photo assessment, finite concentrate capacity, proposed fill trials, particle-size classification, research references and mass-balance tests. Mode 3 is a successful reported visual trial, not a measured recovery benchmark. More speed or time is not assumed to improve recovery. No geometry changed.

Everything below is chronological history and its old preset tables/limits are superseded by the current README.

---

# Historical amendment: tripled motion trial

The user reported that the first retune below was still too slow. The current Config.h and README supersede its preset table: speed ceilings 540/810/1080 degrees/s; rocking acceleration 7200/14400/21600 degrees/s²; spin 90/135/180 RPM; spin acceleration 1800/2700/3600 degrees/s². Each is exactly three times the preceding revision. Amplitude, cycle counts, holds, pauses and pump settings are unchanged.

This is a user-requested escalation for bench testing, not a research-derived optimum. The old 60 RPM limit and 4000 pulses/s budget below describe the preceding revision only. Current pulse budget is 12000/s, with requested maximum 9600/s. The existing cooperative engine is retained; actual timing at the new rate requires measurement. A nominal 104-microsecond service deadline at HIGH is not proven by a host simulation.

The short rocking strokes are now triangular: continuous frequencies 4.33/5.30/5.81 Hz, peak rocking speeds about 416/679/930 degrees/s. Tripling acceleration and ceiling speed does not triple stroke frequency. Agitation windows shorten to about 4–5 seconds and water per batch may change. The motor can stall rather than move faster; verify shaft and bowl marks track the command before increasing the mode.

At 90/135/180 RPM and radius 29 mm, radial acceleration is approximately 0.263/0.591/1.051 g, and ideal steady free-water rise is 3.81/8.57/15.24 mm. MEDIUM and HIGH exceed the approximately 106.6 RPM frictionless inward-sliding boundary discussed below. Even LOW has reduced inward margin. These bursts can expel heavies as well as gangue; collect all tailings. The packed central pocket and zero-motion axis limitations remain. No geometry or hardware rating has been validated by this escalation.

Apply the bench procedure below with the **current README's values**: LOW now commands ±12 degrees and 90 RPM. The previous timing results are historical. New validation is recorded in VALIDATION.md.

---

# Loaded-bed motion revision, 2026-09-27

## Finding and hypothesis

The reported LOW barely moves and HIGH washes the surface without mobilizing the loaded central pocket. The previous presets were gentle commissioning trials, not calibrated separation settings. Their arithmetic was internally consistent, but inadequate agitation is a plausible interpretation of the physical observation. A loose hub, incorrect microstep selection, low driver current or missed steps can produce similar symptoms; software has no encoder.

Hypothesis: larger strokes with much higher finite angular acceleration create relative motion between bowl and wet bed, allowing rearrangement during rocking and settling during the quiet period. This is an experimental retune, not CFD or a demonstrated recovery improvement. Symmetric torsional rocking is not a Wilfley table's asymmetric linear motion, nor a hydraulic jig's vertical bed expansion. It does not guarantee inward transport or fluidization.

## Geometry actually used

`mechanical/gold_poc_v2/build_v2.py`, P06 revolved profile: 64 mm outside diameter; working slope from radius 10 mm at Z=87 to radius 29 mm at Z=94; slope atan(7/19)=20.225°. Central pocket has radius about 8 mm, wet floor Z=76 and rounded entrance near Z=86–87. Its nominal cylindrical volume is about 2 mL before fillets/optional insert; a gram or two is significant in this pocket. The inlet at radius 22 mm washes the slope, not directly through the packed sump. The replacement hub/base/lid leave P06 unchanged.

“Full” is treated here as a packed central pocket, not a dilute film. Dry mass alone does not determine bed depth, porosity, yield stress or required torque. A full pocket has little room for bed dilation, and at the exact rotation axis both tangential and centrifugal acceleration vanish. Increasing torsional motion cannot eliminate that geometric limitation. If a packed plug persists, stop feeding and recover/clear the pocket; this design has no continuous concentrate discharge. Faster spinning does not make it a self-emptying center trap.

## Calculations and selection

For interior travel D=2A degrees, acceleration a and ceiling v: triangular travel time is 2 sqrt(D/a) when D<=v²/a; otherwise trapezoidal time is D/v+v/a. A full cycle takes twice that travel time. Old modes all give approximately 0.866 Hz; their peaks were only 34.6/69.3/103.9 degrees/s, below the configured ceilings.

| Quantity | LOW | MEDIUM | HIGH |
|---|---:|---:|---:|
| Amplitude, degrees | ±12 | ±16 | ±20 |
| Speed ceiling, degrees/s | 180 | 270 | 360 |
| Acceleration, degrees/s² | 2400 | 4800 | 7200 |
| Acceleration increase | 20× | 20× | 20× |
| Interior frequency, Hz | 2.40 | 2.86 | 3.10 |
| Peak-to-peak arc at pocket radius 8 mm, mm | 3.35 | 4.47 | 5.59 |
| Tangential acceleration at 8 mm, g | 0.034 | 0.068 | 0.103 |
| Tangential acceleration at 29 mm, g | 0.124 | 0.248 | 0.372 |
| Rocking pulse ceiling, pulses/s | 1600 | 2400 | 3200 |
| Spin RPM | 30 | 45 | 60 |
| Spin radial acceleration at 29 mm, g | 0.029 | 0.066 | 0.117 |
| Ideal rotating-water rise, center to 29 mm, mm | 0.42 | 0.95 | 1.69 |

Use a_t=r*alpha, a_r=r*omega², and delta_h=omega²*r²/(2g), with radians and SI units. Water-rise estimates assume steady rigid-body rotation of a free liquid; these short bursts and packed slurry need not reach it. They are screening quantities, not predicted flow fields.

At 300 RPM, a_r is 2.92g at 29 mm and ideal rise is 42.3 mm. Ten times RPM gives 100 times centrifugal acceleration. The frictionless inward-sliding boundary on this slope at 29 mm is approximately 106.6 RPM: omega²*r=g*tan(slope). Friction lowers the inward-motion margin; even 60 RPM is not guaranteed to transport grains inward. A high-speed centrifugal concentrator retains heavies at the outside and uses different geometry/fluidization. Its RPM cannot be transferred to a center-collection bowl.

The selected 20× acceleration is a falsifiable trial suggested by the observation, not a material-dependent calculation of the exact threshold. Rotor inertia, entrained water and friction matter more than the 1–2 g sample alone. For illustration only, I=2e-5 kg m² at HIGH's 125.7 rad/s² requires 0.00251 N m before friction/fluid torque. Actual inertia and available dynamic motor torque are unmeasured; holding torque would not establish the latter. Exact Moons motor phase current/inductance/torque curve remains unverified.

All new full strokes reach their configured speed ceiling in ideal continuous motion. Keep finite braking before reversal. More aggressive does not mean instant direction changes at speed. There is no vertical undulation actuator in this build. The 18/24/30 cycles retain about 8–10 seconds of agitation; quiet settling is 3 seconds in every mode, not a claim that fine gold fully settles through mud in 3 seconds. Pump timings are unchanged; shorter phase durations change total delivered water, so collect and measure complete batches again.

## Pulse generation and practical limits

At the existing 3200 pulses/revolution, 60 RPM and 360 degrees/s each need 3200 pulses/s (312.5 microseconds per pulse). The compile-time ceiling of 4000 pulses/s is a chosen software budget, not a measured board limit or motor rating. AccelStepper emits at most one step per run() call and cannot catch up automatically after a delayed loop. Timing must be measured under the actual firmware. Wi-Fi stays disabled; status transmission is deferred until motion is at rest so formatting does not disturb the faster strokes. Software still services stop input during motion.

## Bench acceptance procedure

1. Mark the shaft/hub/bowl and verify they move together. With power isolated, check attachment and microstep wiring. Confirm the motor current rating before adjusting driver current; do not infer it from the NEMA frame.
2. Run water-only LOW with the lid secured and outlet clear. Film the marked bowl in slow motion. Verify about 24 degrees endpoint-to-endpoint rocking, approximately 2.4 interior cycles/s, and a 30 RPM spin plateau. The plateau is short; use video or a pulse counter, not a handheld RPM guess. Verify STEP rate with a logic analyzer if available.
3. Run the same measured wet sample and flow in LOW, then MEDIUM, then HIGH only if actual motion tracks commands. Keep every discharge in a separate labeled catch container. Stop for rattling, lost motion, hub slip, contact, excessive splashing or overheating; increasing commanded acceleration during a stall reduces real motion.
4. Observe grains against the bowl wall, not just the water. Success at this stage means internal rearrangement/bed dilation rather than a rigid rotating plug. Repeat with a partly filled pocket as a diagnostic control against the fully packed case. Log dry mass, fill depth, particle size, clay content and collected water per complete batch.
5. Determine recovery separately using a known recoverable tracer/sample and inspection of all tailings. Visible agitation alone is not separation. Compare retained/discharged heavy fraction and gangue removal before accepting a preset. Do not feed continuously into an already packed sump.
6. If verified HIGH motion still only moves surface water, the working hypothesis failed: dispersing cohesive feed, providing expansion space, or redesigning agitation/water entry is necessary. Do not automatically escalate to 300 RPM. Geometry changes require another prototype trial; no unvalidated reprint is introduced here.

## Research basis and scope

- [AccelStepper class reference](https://www.airspayce.com/mikem/arduino/AccelStepper/classAccelStepper.html): cooperative stepping, finite acceleration, open-loop lost-position behavior and platform-dependent pulse-rate limits. Pinned implementation is 1.64.
- [Knelson particle tracking study, University of Birmingham](https://research.birmingham.ac.uk/en/publications/particle-motion-observed-inside-a-laboratory-scale-knelson-concen/): primary experiment on a 3-inch bowl at 60g; emphasizes dependence on residence time, slurry and profile. This is evidence that the centrifugal device is a different operating regime, not support for our chosen RPM.
- [A mechanistic approach to modelling Knelson concentrators](https://www.sciencedirect.com/science/article/abs/pii/S0892687504002171): searchable publisher abstract describes outward feed motion and fluidization to prevent compaction. Full text was not available in this review; no quantitative settings were transferred.

The formulas above are elementary kinematic/equilibrium screening. No measurement of slurry viscosity, particle distribution, torque-speed curve or recovery was supplied. Those omissions prevent claiming an optimized setting.

## Software timing check

`tools/motion_sim/` runs the real pinned AccelStepper 1.64 with a simulated 5-microsecond service interval and stubbed GPIO. Observed recurring frequencies were 2.463 / 2.935 / 3.165 Hz; spin durations 1.077 / 1.081 / 1.084 seconds, with requested peaks 30 / 45 / 60 RPM. Differences from continuous formulas reflect the discrete library ramp and rounding. This does not simulate ESP8266 execution cost, interrupts, motor torque or fluid motion. CI compiles this check after the firmware build using the installed library source.

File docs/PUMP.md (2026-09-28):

# Water pump: Kamoer NKP-DC-S10B

The supplied pump label reads **12 V, 5 W**. Use regulated 12 V DC. Dividing the nameplate values gives approximately 0.42 A; this is not a measured startup or stall current. The exact flow rate is unverified and must be measured with your tubing, lift and brass outlet installed.

## Switching circuit

Pump circuit

Use **one IRF9540N P-channel MOSFET, one 2N3904 NPN transistor and one 1N5822 Schottky diode** from the photographed inventory. This replaces the previous AO3400A low-side circuit with a high-side switch. Do not reuse the old source/drain or diode connections. The existing firmware remains active HIGH: D1 HIGH turns the pump ON; LOW or a floating/reset GPIO turns it OFF through the external resistors.

| Part / connection | Destination |
|---|---|
| Q1 IRF9540N source (pin 3) | Fused regulated +12 V |
| Q1 drain (pin 2 and metal tab) | Pump positive, the switched-positive net |
| Pump negative | Common GND |
| R3: 10k ohm | Q1 gate to Q1 source (+12 V); holds switch OFF |
| R4: 1k ohm | Q1 gate to Q2 collector |
| Q2 2N3904 emitter | Common GND |
| R1: 4.7k ohm | NodeMCU D1 / GPIO5 to Q2 base |
| R2: 100k ohm | Q2 base to Q2 emitter / GND |
| 1N5822 cathode (band) | Pump positive / Q1 drain, NOT constant +12 V |
| 1N5822 anode (unbanded end) | Pump negative / GND |
| 100 nF ceramic | Across pump terminals, close to motor |
| 100 µF, 25 V electrolytic | + to fused constant 12 V, − to GND near switch |
| Supply negative | NodeMCU GND and stepper supply GND |

All four resistors can be ¼ W. The capacitor values are retained from the existing circuit; their availability was not established by the transistor/diode photos. Choose the branch fuse from measured startup current and wire capacity.

**Physical pins:** IRF9540N TO-220, printed face toward you and leads down: left gate, center drain, right source. Its exposed tab is drain (switched pump positive), not ground. A typical onsemi 2N3904 TO-92 is E–B–C with flat face toward you and leads down. The kit manufacturer is unverified: check actual markings/manufacturer pinout or a component tester before soldering. Do not assume a BC337 or 2N2222 has the same lead order.

**Why this circuit:** the photographed IRF-series N-channel parts are not selected for direct 3.3 V gate drive. The 2N3904 instead pulls the P-channel gate down through 1k. With 12 V and approximately 0.2 V at the collector, gate voltage is about 1.27 V, giving VGS ≈ −10.73 V. IRF9540N on-resistance is specified at −10 V (0.117 ohm maximum at the datasheet test conditions). At the nameplate-derived 0.417 A, the estimated conduction loss is about 0.020 W at that resistance; this is not a startup/stall or hot-device guarantee. GPIO base current is about 0.55 mA; steady collector current is about 1.07 mA. No firmware inversion is required. This resistor gate drive is for the existing slow timed bursts, **not high-frequency PWM**.

The 1N5822 is rated 3 A / 40 V under datasheet conditions. Keep its flyback loop short. The kit's 1N4148 is not the motor flyback choice. No Zener is required for this regulated-12-V circuit; do not substitute a higher supply voltage. Power NodeMCU VIN from the L7805 5 V output per [the shared-supply guide](WIRING.md). Never apply 12 V to VIN, GPIO or 3V3; disconnect external VIN before USB. Pump power bypasses the L7805.

### Electrical checkout

1. Power off: verify Q1/Q2 pin identities, separate nets, resistor values, diode band and capacitor polarity. Keep the pump disconnected.
2. Apply regulated 12 V with current limiting. At LOW/reset, Q1 gate should be approximately 12 V relative to GND (VGS ≈ 0). During the existing `p` command it should fall to about 1.3 V (VGS ≈ −10.7 V), then return to 12 V. An unloaded drain may float; temporarily connect 10k from drain to GND to check output switching.
3. Power off and connect the pump and its protection. Test with water using `p`, then reset the controller and verify the pump stays OFF. Check startup current, rail dips and device temperature before longer operation. Hardware testing has not been performed for this design.

Shared 12 V and regulated 5 V rails

A regulated 12 V supply with about 2 A capacity is a reasonable pump-branch starting point, subject to measured startup current. If sharing the stepper supply, it must be 12 V with enough combined capacity. A higher-voltage stepper supply requires a separate regulated 12 V supply or suitable buck converter for this pump. Add a branch fuse selected for measured startup current and wire capacity. Route pump current through secure soldered/terminal connections, not GPIO or thin breadboard rails.

The photo does not establish motor-terminal polarity for the desired pumping direction. Test briefly with water and the protected circuit; reverse the two motor leads with power off if needed. The flyback diode always stays band-to-switched-pump-positive / Q1 drain. Do not reverse the supply or diode.

## Automatic operation

The pump starts OFF. Starting the machine also enables timed water bursts while the bowl rocks. It turns off during centering, settling, spinning, rest and stopping. Controlled stop shuts water off immediately while the bowl decelerates. Automatic water resumes on the next rocking batch. It does not pulse anew at every direction reversal.

| Active preset | Pump ON | Pump OFF |
|---|---:|---:|
| LOW | 0.50 s | 4.50 s |
| MEDIUM | 0.75 s | 4.25 s |
| HIGH / TRIAL4 / TRIAL5 / TRIAL6 | 1.00 s | 4.00 s |

Each rocking batch begins with an ON interval. These are full-12-V bursts, not reduced-voltage PWM. Short phases can truncate intervals, so total flow cannot be inferred simply from a nominal duty percentage. Edit `PUMP_SCHEDULE` in `include/Config.h` after measuring. Start with LOW and observe drainage; the defaults are experimental, not a hydraulic recovery model.

Serial Monitor at 115200 baud accepts single characters:

| Command | Action |
|---|---|
| `p` | Prime for 3 seconds, only while machine idle |
| `c` | Calibration run for 30 seconds, only while idle |
| `w` | Toggle automatic water; turns current pump output off |
| `x` | Cancel water immediately and stop motion with deceleration |
| `!` | Cancel water and immediately disable stepper drive |
| `?` | Report motion and water status |

Repeated `p`/`c` cannot extend an active manual run. A long button press that starts motion cancels manual dispensing first. A short press still selects the motion/water preset. Automatic-water preference resets to enabled at boot; no flash writes occur.

## First water test and calibration

1. Install the new lid following [the illustrated lid instructions](../mechanical/lid_water/README.md). Secure hoses independently of the lid.
2. With motion stopped, put the outlet in a measuring cup. Use `p` to prime the complete line. Check direction and leaks.
3. Use `c`; collect 30 seconds of water. Measured mL multiplied by two estimates continuous full-on mL/min at this lift. Startup and short-burst behavior can differ.
4. Reinstall the brass tube to its positive seat and run LOW with water only. Measure delivered water over several complete batches and check the catcher drains faster than inflow. Adjust burst duration if needed.
5. Check MOSFET, wiring and pump temperature and startup reliability before adding material. Keep the clean-water reservoir below the outlet where practical; test for siphoning after shutdown. Stopping the motor is not a certified fluid shutoff valve.

There is no flow sensor, reservoir sensor or overflow switch. Software cannot detect an empty reservoir, blocked drain, disconnected tube or failed switch. Unattended operation and gold recovery have not been validated.

## Longer agitation and six modes

Modes 1–3 now double rocking counts; modes 4–6 retain roughly 10 seconds agitation and use HIGH water intervals. Longer agitation changes delivered water per batch even though ON/OFF intervals are unchanged. Measure complete-cycle delivery again; see [OPERATION.md](OPERATION.md) for feeding and cleanup.

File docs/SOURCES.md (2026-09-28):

# Sources and engineering decisions

Reviewed 2026-09-26.

- Hardware photo supplied by Ryan: module label ESP-12E / ESP8266MOD. Red driver is visually consistent with an A4988 carrier, but identification is provisional because its IC is covered.
- Existing project configuration: https://github.com/darkmatter2222/ESP8266_MPU6050_Seismometer/blob/main/platformio.ini
- PlatformIO NodeMCU board: https://docs.platformio.org/en/latest/boards/espressif8266/nodemcuv2.html
- A4988 carrier wiring, current-limit equation, supply range, microstep selection and LC-spike precautions: https://www.pololu.com/product/1182
- A4988 datasheet: https://www.pololu.com/file/0J450/A4988.pdf
- AccelStepper API, `run()`, `stop()`, output inversion and open-loop limitations: https://www.airspayce.com/mikem/arduino/AccelStepper/classAccelStepper.html

The 64 mm bowl's roughly 20.2-degree working slope motivated conservative spin presets, but neither the angle nor ideal sliding-force calculations determine selective gold recovery. Centrifugal acceleration points outward. A short spin is an experimental wash/ejection stage, not a proven density filter. No CFD, motor torque curve, physical timing measurement or recovery trial was performed for this firmware.

Continuous position commands use constant-acceleration triangular/trapezoidal profiles. Acceleration changes abruptly at ramp boundaries; a jerk-limited S-curve is not implemented. For a rest-to-rest full swing of distance 2A and acceleration a, when triangular, time is 2*sqrt(2A/a). A complete interior oscillation takes approximately 4*sqrt(2A/a). Spin distance v*v/a + v*T allows equal acceleration/deceleration ramps and T seconds nominally at speed. The three initial presets keep requested pulse rate at or below 1600 Hz under the assumed 200 x 16 steps/revolution.

## Pump and switch sources

- Supplied pump photograph: Kamoer NKP-DC-S10B, 12 V, 5 W. Exact flow and stall current are not shown.
- [Kamoer NKP manufacturer catalog](https://pdf.directindustry.com/pdf/kamoer-fluid-tech-shanghai-co-ltd/nkp-peristaltic-pump-data-sheet/242598-1017446.html): multiple motor/tube variants; a family flow range does not establish this unit's flow.
- [Infineon IRF9540N datasheet](https://www.infineon.com/assets/row/public/documents/24/49/infineon-irf9540n-datasheet-en.pdf): P-channel TO-220, G/D/S pins; on-resistance specified at −10 V gate drive.
- [onsemi 2N3903/2N3904 datasheet](https://www.onsemi.com/pdf/datasheet/2n3903-d.pdf): 2N3904 NPN, reference pinout and switching ratings. Kit manufacturer is unverified.
- Inventory photographs reviewed 2026-09-27: IRF9540N, 2N3904 and 1N5822 labels visible. These replace the previous AO3400A selection.
- [Vishay 1N5820–1N5822 datasheet](https://www.vishay.com/docs/88526/1n5820.pdf): 1N5822 is 3 A / 40 V.

Pump timings are conservative experimental starting settings, not results from fluid simulation. The lid geometry is digitally checked but not physically leak-tested.

## 12 V / L7805 power revision (2026-09-26)

- ST L78 datasheet, TO-220 pinout, application bypass capacitors, minimum load and thermal data: https://www.st.com/resource/en/datasheet/l78.pdf
- Original NodeMCU DevKit v1.0 schematic (reference only; clone isolation is not established): https://github.com/nodemcu/nodemcu-devkit-v1.0/blob/master/NODEMCU_DEVKIT_V1.0.PDF
- New breadboard photographs show ESP8266 ESP-12E, red driver carrier, heatsink-mounted three-lead regulator and tactile button. Regulator marking and driver IC remain obscured; no hole-by-hole pinout is inferred.

## Feeding, saturation and particle size review (2026-09-27)

See [OPERATION.md](OPERATION.md#research-references-and-limits) for primary studies and manufacturer descriptions, access limitations, and the distinction between transferable mechanisms and unvalidated local fill/screen settings. Reproducible stationary cavity integration is in `tools/check_capacity.py`; it is not CFD or usable concentrate capacity.

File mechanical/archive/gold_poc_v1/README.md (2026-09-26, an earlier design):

# Central-trap gold concentrator — POC v1

Experimental mechanical prototype. Not a validated gold recovery machine, a pressure vessel, or a rated centrifuge. CAD validity and mesh closure do not establish printed leak resistance, dynamic balance, or recovery. No CFD or multiphase particle simulation was performed. All dimensions are millimeters. STLs are separate parts, in mm, translated onto Z=0; STEP files preserve assembly coordinates.

## What is included

128 mm OD rotating bowl; central 28 mm diameter sump approximately 20 mm deep (about 12 mL before the collar); removable 16 mm throat collar; one-piece wet bowl with blind fastener holes; a separate 166 mm OD catcher, drain and splash lid; bearing-supported drive; open motor cradle with cable access. Overall envelope approximately 170 W × 187 D × 203 H, including drain and lid. All normal frame/rotor fasteners are M4. Standard NEMA17 motor mounting threads are M3, so four M3 screws are required at that interface.

The bowl is a deliberately smooth baseline with a roughly 21-degree outward-rising working slope. No spiral pumping vanes are included: their net inward transport under reversing motion has not been established. The deep pocket and overhanging collar shelter sediment but do not act as a one-way valve. Sand and clay can fill the sump. Capture and retention are separate experimental questions.

## Print list

| File | Quantity | Orientation / supports |
|---|---:|---|
| 01_motor_base.stl | 1 | Feet down; support underside of elevated motor deck. |
| 02_bearing_stand.stl | 1 | Legs down; support underside of deck. Keep bearing bores clean. |
| 03_splash_catcher.stl | 1 | Floor down; supports for drain spout and upper external lugs. |
| 04_catcher_bracket_print4.stl | 4 | Flat; inspect underside captive-nut recess. |
| 05_sealed_bowl.stl | 1 | Flat bottom flange down; external supports beneath flared bowl and drip skirt. No supports on the working surface. |
| 06_trap_collar.stl | 1 | Flip so flat tab tops lie on bed; inspect collar throat and remove burrs. |
| 07_drive_hub.stl | 1 | Flip large flange onto bed. Clear horizontal insert bores carefully. |
| 08_insert_coupon.stl | 1 | Flat. Five blind bores left-to-right at X=-24,-12,0,12,24 are 5.2,5.4,5.6,5.8,6.0 mm. |
| 09_bearing_spacer.stl | 1 | Flat; bore vertical. Contacts inner bearing races only. |
| 10_bearing_retainer.stl | 1 | Flat. |
| 11_splash_lid.stl | 1 | Flat. |

Suggested starting print process: PETG, 0.2 mm layers, 6 perimeters, at least 8 top/bottom layers, 40–60% infill; use symmetric slicing settings for the rotor. These are process suggestions, not strength qualification. The bowl and catcher use approximately 4 mm primary wet walls. Inspect slicer previews, especially supported surfaces and small bores. Do not use a visibly warped rotor.

Print the fit coupon first. Default insert bore is 5.6 mm, intended as a trial for approximately 6 mm OD × 6 mm long M4 inserts. Your inserts may require another diameter. Change INS in build.py and regenerate if needed. Do not force an oversized insert into a thin boss. Neither STL dimensions nor a nominal M4 designation establish actual insert fit.

## Nonprinted hardware

- Your 5 mm shaft stepper, assumed standard NEMA17: 42 mm square face, 31 mm mounting-hole pitch, approximately 22 mm pilot, nominal 40 mm body. These dimensions MUST be measured before printing the frame. A 5 mm shaft alone does not verify them. Open cradle accommodates body length up to about 48 mm beneath the mounting face.
- Four M3 motor screws, typically M3×10 for a 6 mm deck and approximately 4 mm engagement; check actual motor thread depth. Do not substitute M4.
- Two 608-2RS bearings, 8 × 22 × 7 mm. Seats are 22.2 mm nominal; fit depends on printer. Retain loose outer races with a suitable bearing retaining compound, keeping it out of the races. Do not distort them by forcing.
- Straight 8 mm steel shaft: nominal 62 mm long, installed from assembly Z=79 to141. Deburr ends. This is a purchased metal shaft, not a printed shaft.
- Balanced clamp-type flexible coupling, 5 mm to 8 mm, approximately 25 mm long and no more than 25 mm OD. Nominal position Z=64..89. Requires about 10 mm grip on each shaft; verify your motor shaft reaches at least Z=74 when its face is at Z=54. If it does not, revise the stand/coupling stack before assembly. Never rely on insufficient shaft engagement.
- M4 heat-set inserts approximately 6 mm long: 24 total (4 base, 4 stand posts, 3 bearing retainer mounts, 4 bowl underside, 3 collar bosses, 2 hub set screws, 4 catcher upper tabs).
- M4 screws: 4×45 mm (stand to base); 3×8 mm (bearing retainer); 4×12 mm (brackets to stand); 4×12 mm plus 4 M4 hex nuts (catcher lower tabs); 4×8 mm (hub to bowl); 3×10 mm (trap collar); 4×8 mm (splash lid); 2×10 mm opposed flat-point set screws or suitable short screws (hub to shaft). Verify tip clearance and insert engagement during dry assembly; washers change the effective lengths. Use equal hardware on opposing rotor positions.
- 18 mm ID flexible drain hose and clamp for the 18 mm OD drain stub, 12 mm internal bore. Leak test this connection.
- Water delivery tubing: lid has two 6.3 mm holes for nominal 6 mm OD tubes, opposite one another at 40 mm radius. Secure tubes externally so they cannot contact the rotor; cap unused hole. The 56 mm central lid opening provides feed/inspection access.
- Current-regulated stepper driver and programmable motion controller, appropriately powered. Exact motor current and pinout remain unverified. Identify winding pairs by resistance with power disconnected; do not infer lead function by color.

## Assembly

1. Measure motor face, pilot, bolt pitch, body and shaft extension. Print coupon and establish insert fit. Mount motor below base deck, face at Z=54. Route its cable through any open side, secure it to stationary structure with a drip loop.
2. Install base inserts; mount coupling to motor shaft. Keep coupling clear of the underside of the bearing stand. Install stand with four M4×45 screws, accessing heads through its top counterbores.
3. Insert lower bearing from above to Z=100..107, then inner-race spacer Z=107..120, then upper bearing Z=120..127. Fit the retainer Z=127..130. Tighten only enough to retain outer race. Check both inner races rotate freely.
4. Slide steel shaft down through bearings into coupling. Fit hub: small nose seats on upper inner race at Z=127; flange upper face Z=143. Tighten its two opposed shaft screws evenly. Set shaft end just below hub flange top; verify axial support is on bearing inner races and hub does not rub retainer. Clamp coupling without pulling shaft axially or preloading bearings.
5. Install four catcher brackets at 45,135,225,315 degrees. Inner bracket holes mount at radius58 to stand posts; outer holes at radius89 hold captive M4 nuts underneath. Fit catcher to outer holes. Its center chimney surrounds the dry hub with nominal 0.8 mm radial clearance. Confirm no contact.
6. Fit four inserts in the bowl's dry underside flange. Attach bowl to hub with M4×8 screws from below the flange. Access is through the open space beneath the catcher. Keep screw tips inside blind holes. The integral rotating drip skirt overlaps the stationary chimney, with nominal 1.5 mm radial and 1 mm vertical roof clearance. This is a splash labyrinth, not a submerged shaft seal.
7. Fit three collar-boss inserts and the collar with three equal M4×10 screws. Collar notches clear the supporting bosses. Hand-rotate and check all clearances. Remove collar for suction-bottle cleanup and inspection; do not drill a drain through the sump.
8. Connect catcher drain. Fit splash lid using four M4×8 screws. Supply water through opposite ports, aimed at the working slope, never directly down the collection throat. Place the complete apparatus in a secondary tray. Secure base using its four 4.5 mm mounting holes.

## Watertightness and balance

The primary bowl is continuous material without through-fasteners; the catcher also has a continuous wet floor and wall. Its mounting holes are on external tabs. FDM walls may still leak. Test both wet parts separately for at least an hour before motor installation. If needed, use a thin, fully cured water-compatible sealing coating, evenly applied to preserve balance; recheck dimensions and texture. Do not assume any coating is food-safe or environmentally suitable without its product instructions.

The catcher drain center is at Z=147, so approximately 1 mm water can remain below its invert. Keep drain unrestricted and catcher liquid BELOW the central chimney top (Z=150). A blocked drain can flood the dry drive. An automatic water shutoff/level sensor is required before unattended operation; not included in this mechanical prototype. The lid is a splash cover with a feed opening, not a sealed containment vessel.

CAD uses concentric surfaces and threefold/fourfold symmetric rotor features. Printed density, inserts, screws, supports and coating can produce imbalance. Static/dynamic balancing has NOT been performed. Test guarded, with all discharge retained. No rated maximum RPM is established.

## First experiments, not production settings

Start with water only: smooth ±5 degrees at 1 Hz. Check for rubbing, leaks, missed steps and tube contact. After successful inspection, compare small known samples under oscillation alone and gentle overflow. Suggested first solids charge is 5–10 g of washed, wet-screened sand. Start with a single approximately 0.5 mm top-size wet screen for this POC; retain oversize and all rinse water. Break clay lumps up separately under water; raw clay is not a valid first performance test. No claim is made that 0.5 mm is optimal for your gold size.

Do not begin with fast ejection pulses. If testing rotation after successful oscillation trials, start at 30 rpm with smooth ramps; 60 rpm is a provisional experimental ceiling, NOT a certified structural limit. Stop if any gold appears in the collected tailings. Compare 0.5–2 Hz and ±3–10 degree oscillation separately rather than increasing all settings together. Water rate must be measured and tuned to remove light material without overwhelming settling; suggested exploratory range 50–200 mL/min only after confirming the drain handles it. No throughput or recovery claim accompanies these settings.

Use real gold of known size/count or measured mass to test recovery. Heavy surrogate grains can check motion but cannot establish flake-gold recovery. Collect overflow in numbered containers. Evaluate both fresh feed capture and whether an early captured sample remains after hundreds of cycles. Record retained black sand, sump packing and motor/driver temperatures. Do not discard any fraction until recovery is understood.

## Mechanics check and research basis

At r=60 mm, radial acceleration is 0.060 g at30 rpm and0.241 g at60 rpm. For the working slope dz/dr=16/42, the ideal frictionless crossover is approximately75 rpm at the outer radius. This ignores water drag, friction, transient circulation and granular contact; it is NOT a selective gold/sand threshold. At r=14 mm, centrifugal acceleration is much smaller, but collected gold can still be resuspended by water exchange. Deep cavities reduce exposure; they do not guarantee irreversible capture.

CAD checks: each exported part must be one valid solid, STL edge closure is checked, and assembled printed-part intersections are checked. Purchased components are dimensionally specified but not certified against the unknown motor. Mesh closure is not a leak test. No fluid dynamics simulation or recovery prediction is claimed.

Relevant primary sources:
- Gold-pan central collection and removable cup precedent: https://patents.google.com/patent/US5788293A/en (patent disclosure, not independent recovery evidence).
- Experimental sediment confinement: https://doi.org/10.1061/(ASCE)EE.1943-7870.0001363 (geometry and local flow influence resuspension; does not validate this bowl).
- Rotating-vessel secondary flow: https://www.mdpi.com/2072-666X/14/11/2024 (tea-leaf aggregation depends on bottom shape and rotation history, not proof of selective gold capture).
- Motor sizing: https://www.orientalmotor.com/technology/motor-sizing-calculations.html

Source CAD is build.py (CadQuery 2.7). assembly.step includes printed components in assembled positions; individual STEP files are editable. To regenerate: python build.py in an environment with cadquery, numpy and matplotlib. Inspect slicer orientation as listed above. Source design is a proof of concept requiring physical fit and process validation.

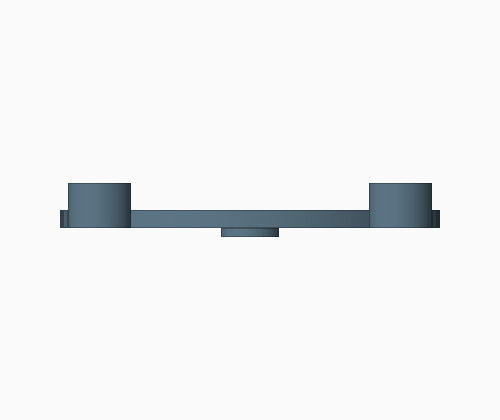
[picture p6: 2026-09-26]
mechanical/gold_poc_v2/assets/P02_motor_deck_view2.png

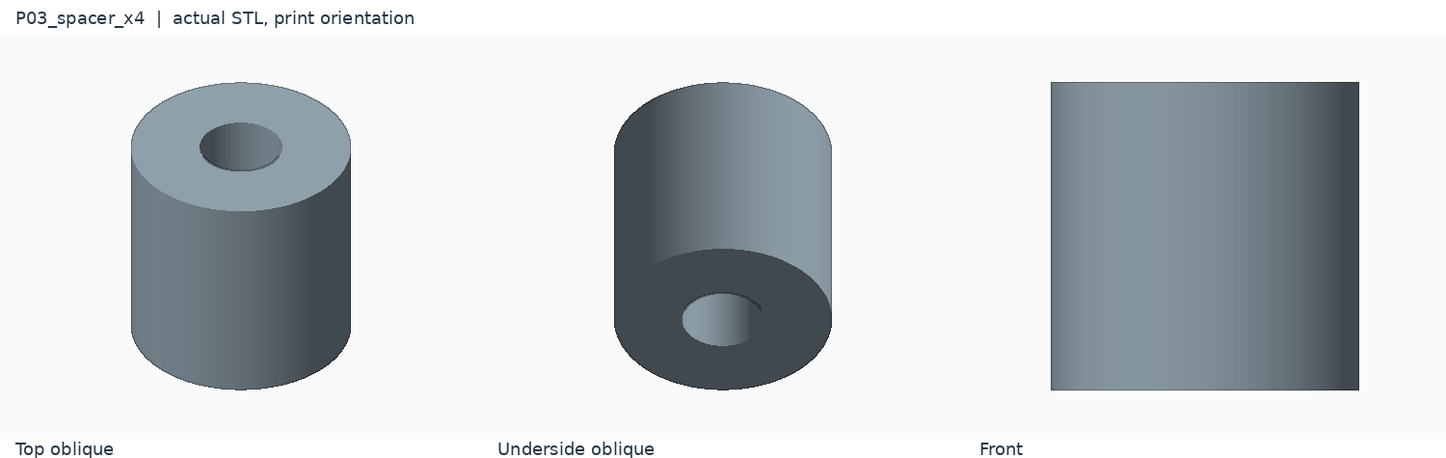
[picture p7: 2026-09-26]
mechanical/gold_poc_v2/assets/review_P03_spacer_x4.png

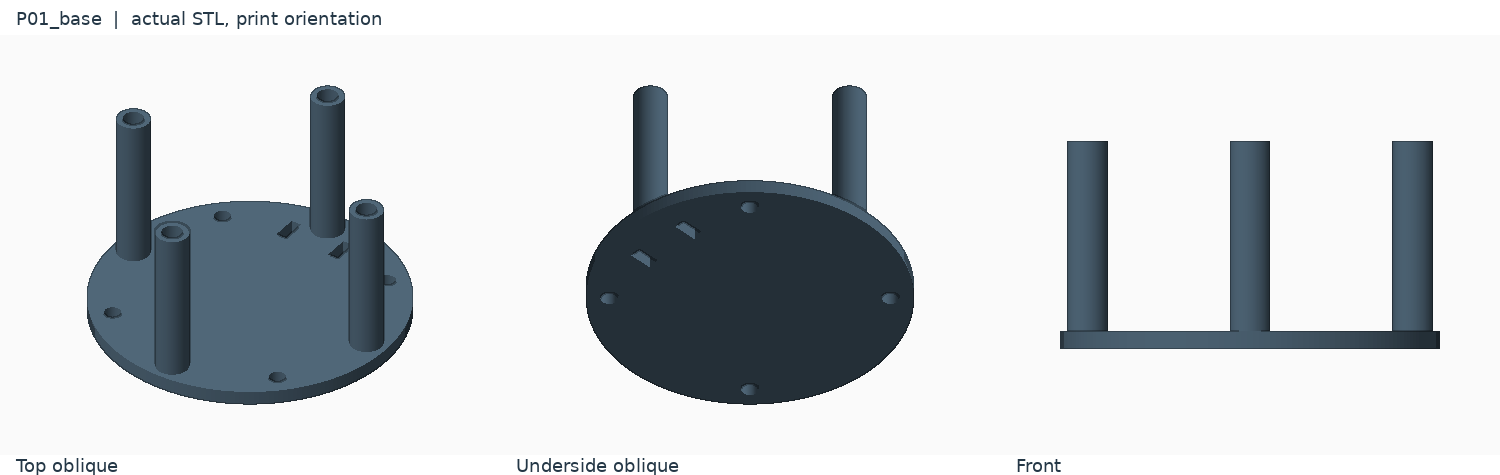
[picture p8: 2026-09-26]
mechanical/gold_poc_v2/assets/review_P01_base.png

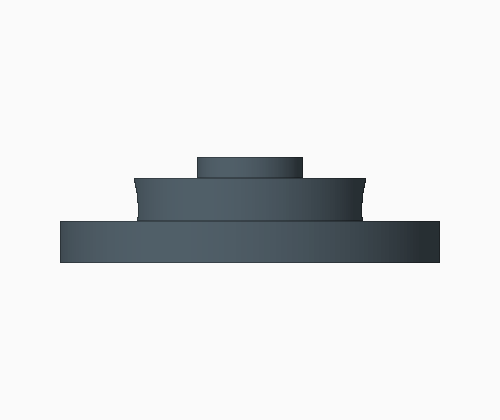
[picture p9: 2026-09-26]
mechanical/gold_poc_v2/assets/P05_drive_hub_view2.png

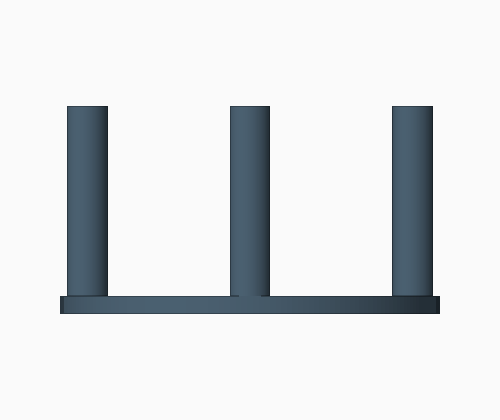
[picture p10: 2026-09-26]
mechanical/gold_poc_v2/assets/P01_base_view2.png

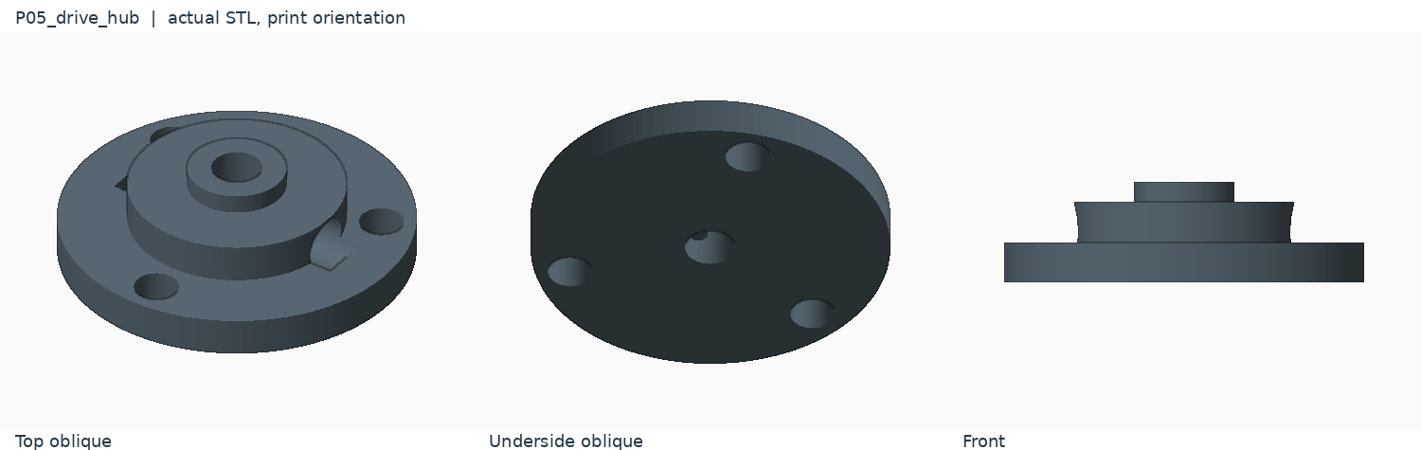
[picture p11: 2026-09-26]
mechanical/gold_poc_v2/assets/review_P05_drive_hub.png

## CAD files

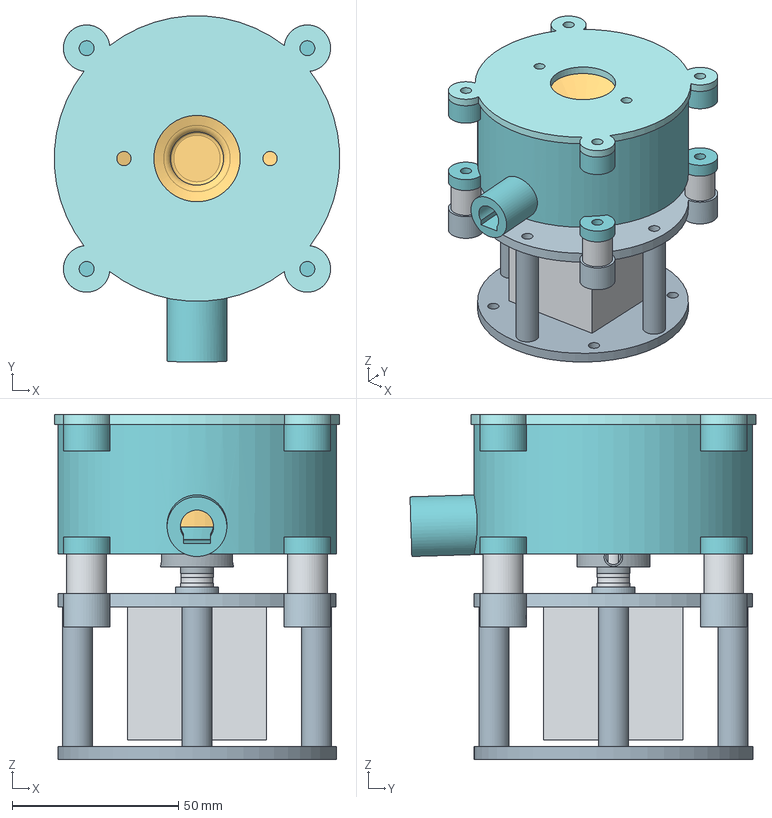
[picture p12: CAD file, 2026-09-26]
mechanical/gold_poc_v2/assembly.step
85.8 x 104.2 x 104.0 mm
P01_base
P02_motor_deck
P04_catcher
P05_drive_hub
P06_bowl
P08_lid
spacer0
spacer1
spacer2
spacer3
motor
thrust_lower
thrust_cage
thrust_upper

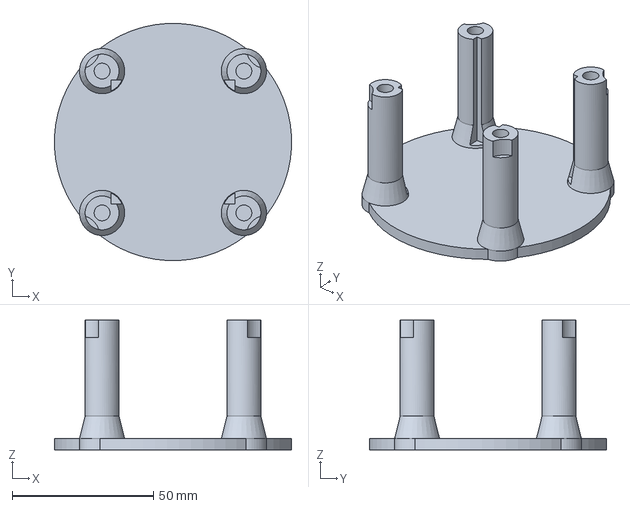
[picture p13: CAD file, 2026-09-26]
mechanical/base_cable_revision/P01_BASE_STRAIGHT_VERTICAL_R3.step
83.9 x 83.9 x 46.0 mm

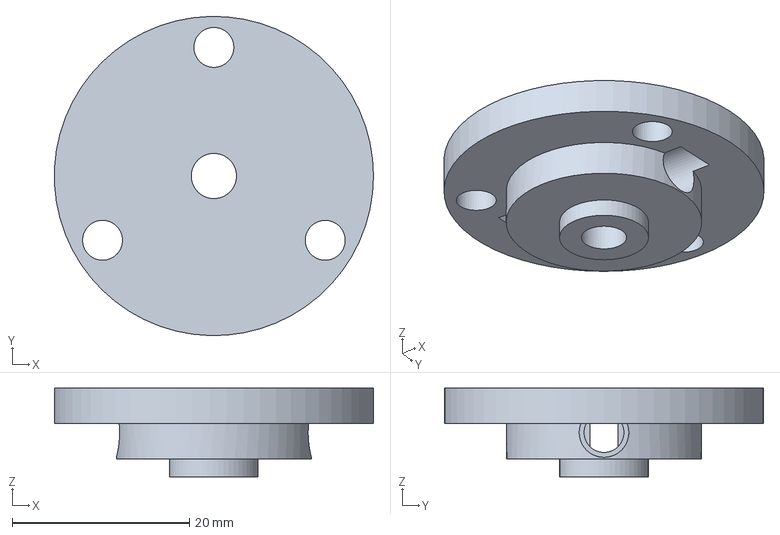
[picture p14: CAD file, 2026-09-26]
mechanical/gold_poc_v2/STEP/P05_drive_hub.step
36.0 x 36.0 x 10.0 mm

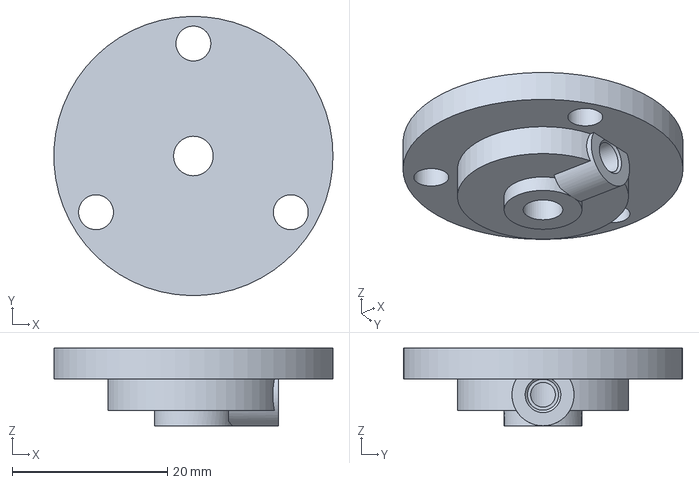
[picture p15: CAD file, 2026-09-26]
mechanical/hub_m3_revision/P05_drive_hub_M3.step
36.0 x 36.0 x 10.0 mm

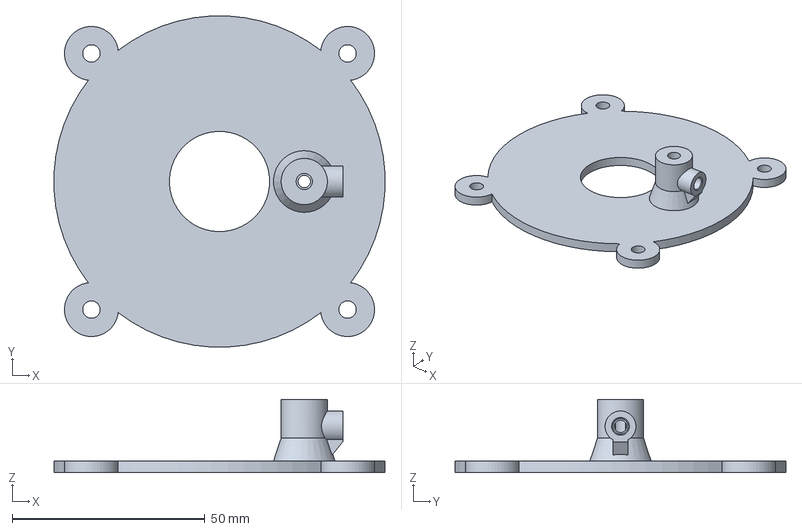
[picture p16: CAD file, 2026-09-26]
mechanical/lid_water/P08_lid_brass_4mm.step
85.9 x 85.9 x 19.0 mm

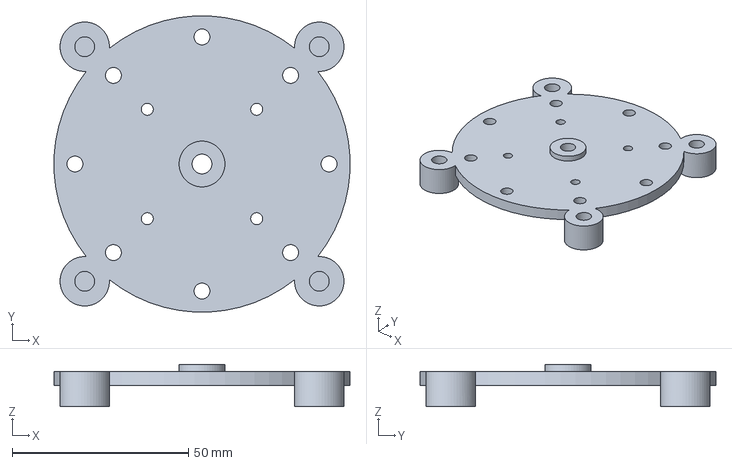
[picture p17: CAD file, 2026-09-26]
mechanical/base_cable_revision/P02_drilled_reference.step
83.9 x 83.9 x 12.0 mm

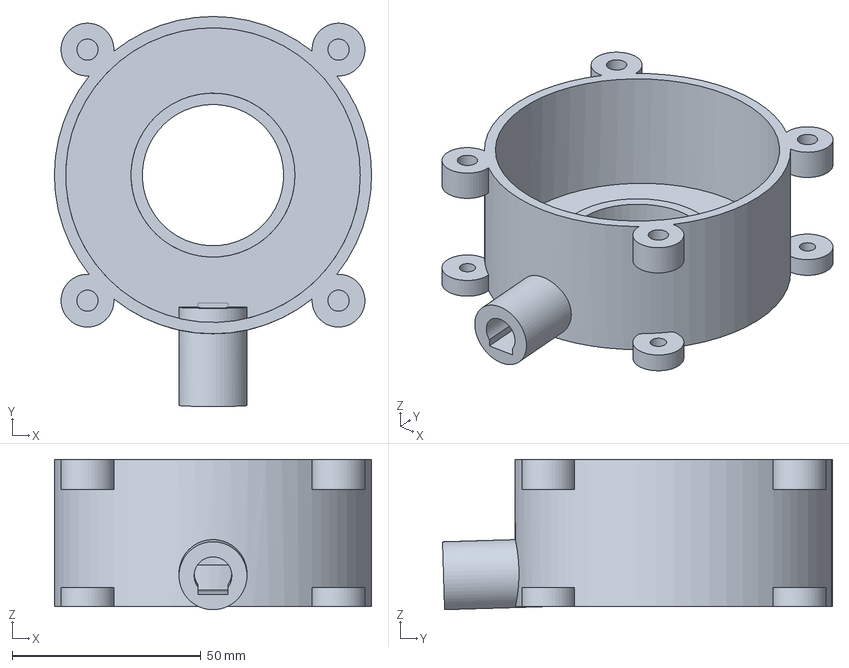
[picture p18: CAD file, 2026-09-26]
mechanical/gold_poc_v2/STEP/P04_catcher.step
84.0 x 103.3 x 39.8 mm

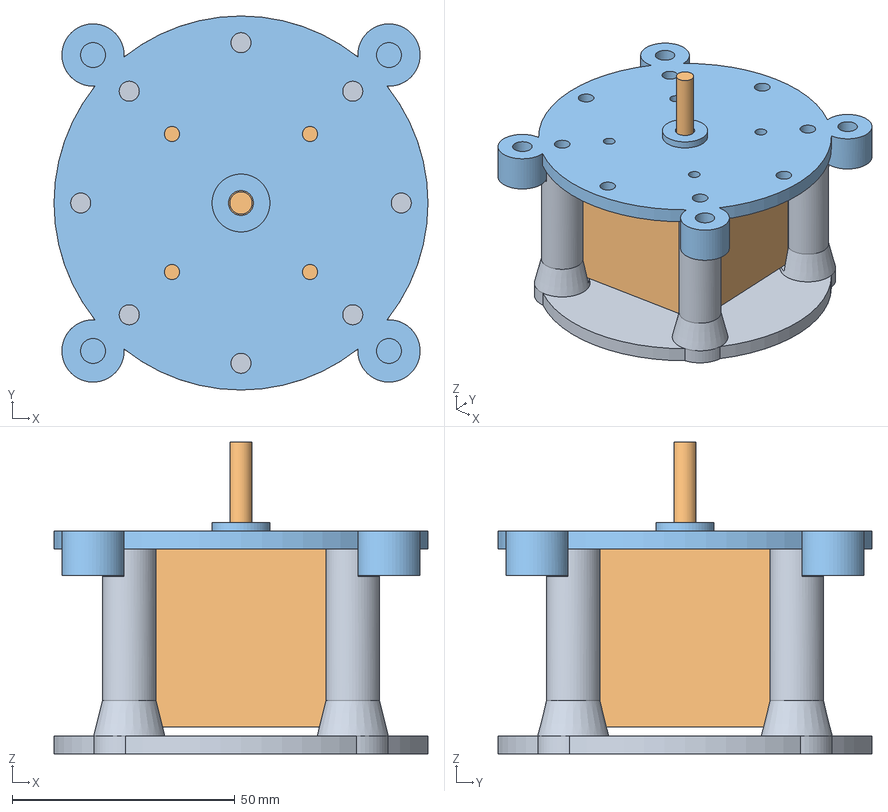
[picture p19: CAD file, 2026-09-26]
mechanical/base_cable_revision/base_motor_deck_reference.step
84.0 x 84.0 x 70.0 mm
revised_base
reference_motor
P02_with_new_holes

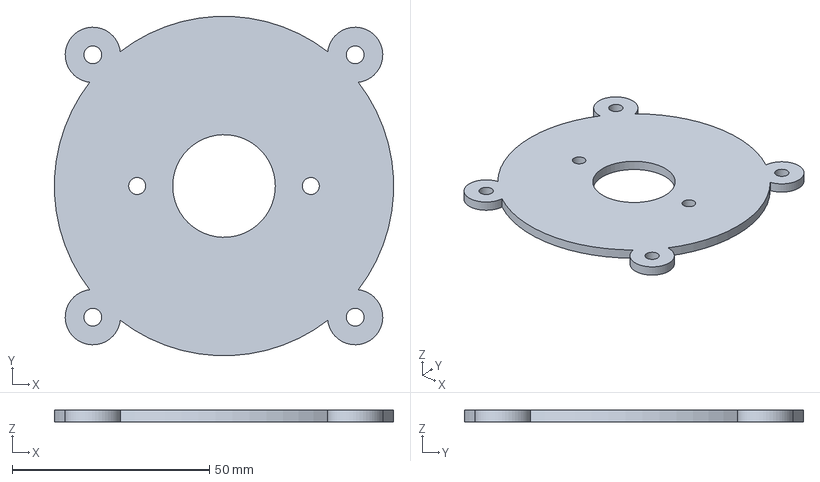
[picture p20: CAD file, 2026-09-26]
mechanical/gold_poc_v2/STEP/P08_lid.step
85.9 x 85.9 x 3.00 mm

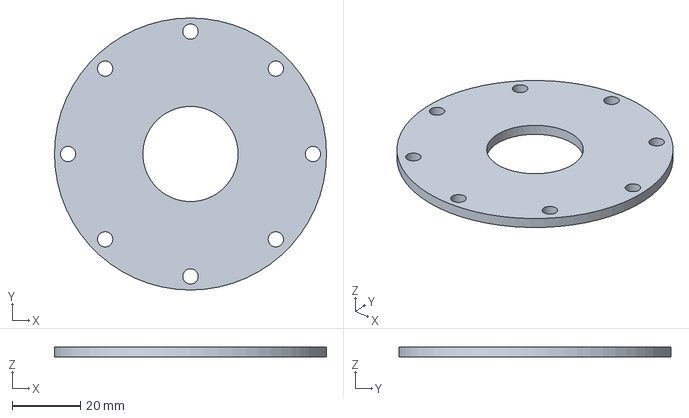
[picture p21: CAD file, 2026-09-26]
mechanical/base_cable_revision/P02_drill_template.step
80.0 x 80.0 x 3.00 mm

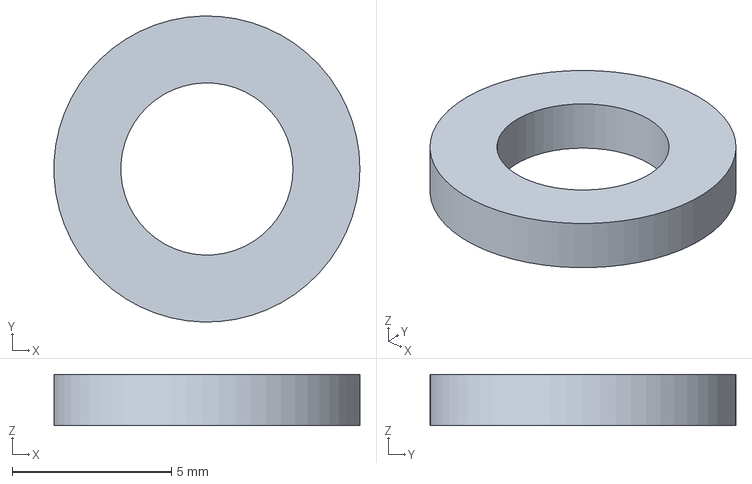
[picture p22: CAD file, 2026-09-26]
mechanical/gold_poc_v2/STEP/H_thrust_cage.step
9.59 x 9.60 x 1.60 mm

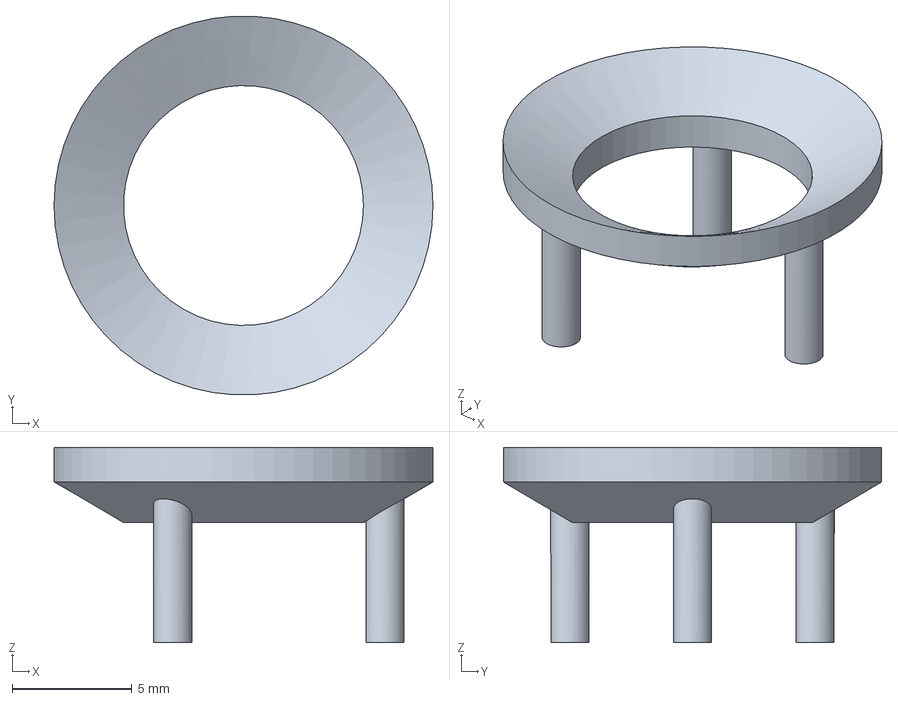
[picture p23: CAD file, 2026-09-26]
mechanical/gold_poc_v2/STEP/P07_optional_trap_insert.step
15.8 x 15.8 x 8.14 mm

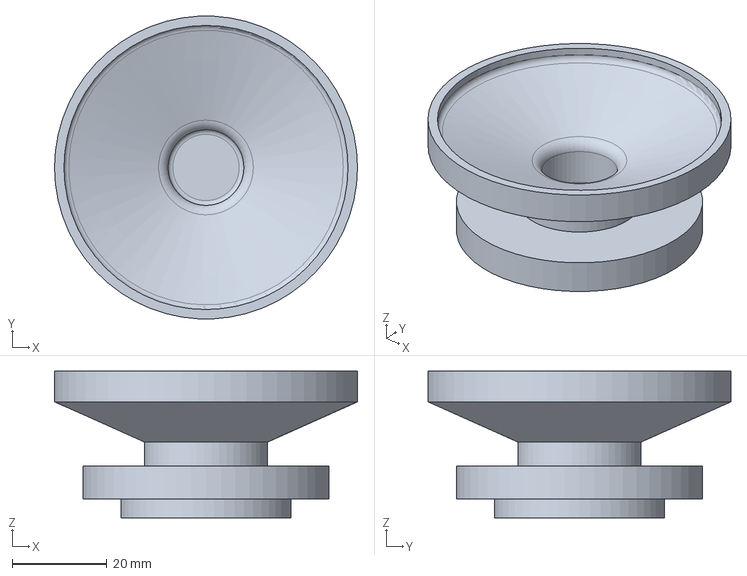
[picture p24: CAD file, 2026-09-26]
mechanical/gold_poc_v2/STEP/P06_bowl.step
64.0 x 63.9 x 31.0 mm

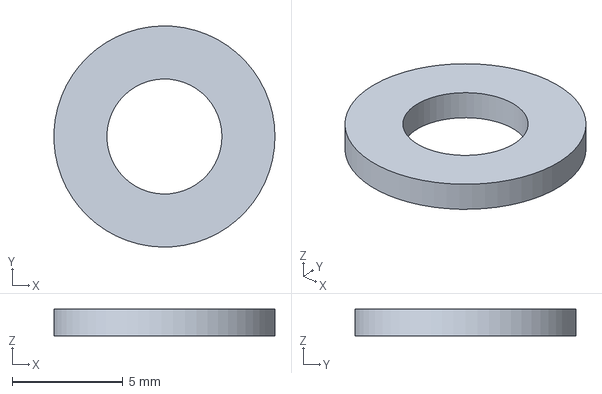
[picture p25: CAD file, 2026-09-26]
mechanical/gold_poc_v2/STEP/H_thrust_lower.step
9.99 x 10.00 x 1.20 mm

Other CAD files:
mechanical/gold_poc_v2/STEP/H_thrust_upper.step
mechanical/gold_poc_v2/STEP/H_motor.step
mechanical/gold_poc_v2/STEP/P03_spacer_x4.step
mechanical/gold_poc_v2/STEP/P02_motor_deck.step
mechanical/archive/gold_poc_v1/01_motor_base.step
mechanical/archive/gold_poc_v1/01_motor_base.stl
mechanical/archive/gold_poc_v1/02_bearing_stand.step
mechanical/archive/gold_poc_v1/02_bearing_stand.stl
mechanical/archive/gold_poc_v1/03_splash_catcher.step
mechanical/archive/gold_poc_v1/03_splash_catcher.stl
mechanical/archive/gold_poc_v1/04_catcher_bracket_print4.step
mechanical/archive/gold_poc_v1/04_catcher_bracket_print4.stl
mechanical/archive/gold_poc_v1/05_sealed_bowl.step
mechanical/archive/gold_poc_v1/05_sealed_bowl.stl
mechanical/archive/gold_poc_v1/06_trap_collar.step
mechanical/archive/gold_poc_v1/06_trap_collar.stl
mechanical/archive/gold_poc_v1/07_drive_hub.step
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

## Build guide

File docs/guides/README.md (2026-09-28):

# Assembly guides and revision amendments

Open [Central_Trap_Gold_POC_v2_Assembly.pdf](Central_Trap_Gold_POC_v2_Assembly.pdf) for the 18-page illustrated compact-kit build guide.

**Apply these updates to that guide:**

1. Replace P05 and its original hub fasteners with the [single-M3-insert drive hub](../../mechanical/hub_m3_revision/README.md). It uses an M3 × 10 mm retaining screw against the 5 mm shaft's D-flat. Existing bowl-to-hub M4 attachments stay as described.
2. Replace P08 with the [supported 4 mm brass-inlet lid](../../mechanical/lid_water/README.md). This adds its own M3 insert and M3 × 8 mm retaining screw, plus a positive tube stop. Keep the original M4 lid mounts.
3. Use the current [electrical wiring](../WIRING.md), [pump circuit/calibration](../PUMP.md) and [firmware operating guide](../../README.md). The older PDF is a mechanical build snapshot and does not contain the later integrated electronics/firmware.

The PDF here is the separately delivered guide recovered from saved project files. The byte-distinct PDF packaged with the original v2 ZIP is preserved inside `mechanical/gold_poc_v2/`. Their extracted text matches; both are retained rather than silently replacing one. The original baseline assembly STEP likewise remains a snapshot, with current replacement STEP files supplied separately.

No regenerated combined assembly PDF or full-assembly STEP is implied. All existing PDFs for this stepper project are preserved. Unrelated centrifuge projects are outside this repository.

## Corrected straight-post base

Replace P01 using the [straight-post base instructions](../../mechanical/base_cable_revision/README.md). Retain the printed P02 deck and drill four new 4.5 mm holes with the supplied template. The original PDF shows the old cardinal post locations and does not include this drilling step. The angled-post interim revision is superseded. The two original rectangular base slots were for cable ties, not a missing assembly part; these and optional bottom anchor holes are removed.

The current electrical guide now uses a shared 12 V supply and L7805 5 V regulator feeding NodeMCU VIN. Follow the [combined wiring diagram](../wiring.svg) and [power/rail guide](../WIRING.md), including the USB power-source changeover procedure.

## Motion settings amendment (2026-09-27)

The original guide's gentle motion settings are superseded by [MOTION.md](../MOTION.md) and the root README. The latest escalation triples the first retune: 90/135/180 RPM spin trials, with rocking acceleration 7200/14400/21600 degrees/s². Existing PDFs and ZIPs remain historical snapshots.

## Six-mode and capacity amendment (2026-09-27)

Current firmware has six modes (90/135/180/195/210/225 RPM) and approximately doubled agitation time. Follow the root README and [OPERATION.md](../OPERATION.md) for current controls, experimental fill targets and size classification. Earlier motion amendments and archived PDFs are historical.

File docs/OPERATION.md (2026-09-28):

# Feeding, concentrate capacity and particle-size control

## What the latest trial establishes

The operator reports that previous mode 3 (180 RPM spin, about 5 seconds rocking) produced the best visible separation so far: muddy/light material left and heavy minerals concentrated centrally. The supplied photo shows a dark central deposit with larger tan grains, fine dark grains distributed on the slope, and grains in the outer catcher. Treat these as the operator's heavy minerals, not an identification of iron. A photograph cannot determine mineral density, gold content, percent recovery, bed depth under water, or whether grains in the catcher were ejected, splashed or spilled during handling.

This is useful evidence of concentration, but concentrate grade and recovery are different. A clean-looking central deposit can coexist with significant loss. A feed reported as 98% heavies is primarily a retention/capacity stress test: if all those minerals are the desired product, almost the entire feed must remain or be collected as concentrate. It is not a representative 10%-heavy feed. Do not treat dark mineral retention as proof of fine-gold recovery.

## There is no validated maximum fill line at mode 3

P06 has a 64 mm outer diameter, a roughly 16 mm central pocket, and a slope from radius 10 to 29 mm over a 7 mm rise (20.2 degrees). Reconstructing the exact curved wet profile gives the following **stationary empty cavity volumes**, excluding optional P07:

| Level above the deepest wet floor | Empty void below level | Meaning |
|---|---:|---|
| 2.5 mm | 0.492 mL | Proposed initial cleanup target for testing |
| 5.0 mm | 0.994 mL | Proposed upper trial cleanup target; not a proven maximum |
| 8.5 mm | 1.698 mL | Start of rounded pocket entrance |
| 11.0 mm | 2.270 mL | Pocket opens onto the main slope |
| 18.0 mm | 11.294 mL | Main slope reaches its outer end |
| 21.0 mm | 19.725 mL | Rim-level cavity volume, not a solids loading allowance |

Reproduce with `python tools/check_capacity.py` (CadQuery 2.7); results are in [CAPACITY_SCREENING.json](CAPACITY_SCREENING.json). These are void volumes, not gold mass or solid mineral volume. A granular bed includes pore water. The optional insert reduces space and changes flow; these values do not apply unchanged with it installed. Print dimensions and leakage require physical checks.

**Practical starting procedure:** start with about 0.5 mL retained, settled concentrate capacity as your cleanup target. In separate measured trials, explore up to about 1.0 mL only if tailings remain acceptable. That corresponds approximately to a bed 2.5–5 mm deep in the bare central pocket, leaving about 6–8.5 mm below the slope entrance. It is an intentionally conservative experimental margin, not a derived safe capacity. Stop earlier if losses increase. Apply at least this same conservative limit to modes 4–6; faster settings do not earn a higher fill line.

Measure the **settled solids bed**, not the water surface or the outer rim. Stop and isolate the machine before measuring. With P07 absent, use a depth probe from the sump floor, or use measured water doses in a clean, stationary bowl to identify approximate heights before tests. A mounded, sloping or compacted bed will not map exactly to the level-volume table. Do not add two or three unmeasured scoops to the photographed load. Clean out and measure what was retained first; the photo cannot resolve how full the submerged sump is.

## Why continuous feeding eventually loses heavies

This is semi-continuous feeding with periodic concentrate removal. It has no controlled concentrate outlet. Retained inventory increases until its finite working capacity is reached. New feed can then cover, remix or displace existing concentrate, while the spin/water removes some old and new particles. Incoming denser grains may replace some lighter grains, but that is not guaranteed to preserve every previously retained heavy grain. The pocket is not a one-way trap.

Commercial equipment distinguishes batch/semi-continuous concentrators from devices with a continuous concentrate stream [1]. Experiments on Knelson beds show heavy-mineral accumulation reaching a maximum and batch duration depending on feed and operating conditions [2]. Their fluidized outer-ring geometry differs from ours; the transferable lesson is finite retained inventory, not a transferable fill depth or RPM.

For planning with actual dry masses:

`retained mass added = feed mass × [heavy mass fraction × heavy recovery + light mass fraction × light retention]`

`time to cleanup ≈ remaining usable retained mass / retained mass added per unit time`

Both retained lights and heavies consume capacity. Packing, size distribution and porosity change the conversion from mass to bed volume; measure it with the actual sample. The equation cannot supply throughput until recovery, retention and feeding rate are measured. True indefinite operation would need a controlled concentrate withdrawal path and revalidation; simply deepening the pocket could produce a harder-to-mobilize bed.

## Your 10 mL example

10 mL total at 10% heavies **by volume** is 1 mL heavies plus 9 mL lights. 10 mL heavies plus 90 mL lights would be 100 mL total. For scale, a US teaspoon is about 4.93 mL: 10 mL is roughly two teaspoons, while 0.5 mL is only about one tenth of a teaspoon. Calibrate a small scoop with water and a graduated syringe rather than guessing a fraction of a household spoon. Percent by mass is different and cannot be substituted without densities. Define whether a scoop is dry bulk, damp settled bulk, or slurry; 10 mL slurry can contain very little solid material.

The following is bookkeeping only: assume component bulk volumes approximately add, every heavy is retained, all lights leave, and use the provisional 1 mL cleanup inventory. Real packing and light retention violate these idealizations.

| Heavy fraction by this volume convention | Ideal total feed before accumulating 1 mL heavies |
|---|---:|
| 1% | 100 mL, accumulated gradually |
| 10% | 10 mL, accumulated gradually |
| 50% | 2 mL |
| 98% | 1.02 mL |

Thus 10 mL of a 98%-heavy sample would contain roughly 9.8 mL of heavies under that convention, far beyond the central pocket. A 10 mL mixed scoop may fit within the total bowl void while still overwhelming the small working pocket. **Total material processed over time is not the same as permissible one-shot dose.** At a 0.5 mL cleanup target, halve the ideal feed quantities. With retained lights, clean out sooner.

## Size uniformity: narrower fractions help; identical grains are not required

Separation depends on particle size, density, shape, liberation, collisions and fluid drag. Larger low-density grains can settle or remain where smaller dense grains escape. For isolated spheres in the low-Reynolds-number Stokes regime, terminal settling velocity scales as `(particle density − water density) × diameter²`. As an illustration, a mineral of density 5 g/cm³ and quartz at 2.65 g/cm³ in water have equal Stokes settling speeds when the quartz diameter is about sqrt(4/1.65)=1.56 times larger. These are hypothetical identities, not identification of this sample, and the formula does not predict the packed bed or millimeter grains.

Primary classifier experiments show separation density varying with particle size [3]. A plant Knelson study reports loss of fine gold associated with coarse gangue/heavy particles [4]. These mechanisms support investigating size effects here; neither establishes a universal screen size for this prototype. Coarse grains in the center do not establish siphoning or prove a defective slope.

Practical test fractions, using measured screen openings rather than mesh labels alone:

| Fraction | Initial treatment |
|---|---|
| Above 1 mm | Retain and inspect/process separately; keep out of initial small-bowl tuning |
| 0.5–1 mm | Separate coarse trial |
| 0.25–0.5 mm | Separate medium trial |
| Below 0.25 mm | Separate fine trial; split further, e.g. at 0.125 mm, if available and losses remain size-dependent |

These are experimental bins, not a certified feed specification. Wet-screen and disperse clay aggregates gently. Keep every oversize and fine/slime fraction: screening does not establish that it is barren. Do not discard wash water containing fines. Do not assume a mixed-size concentrate can be cleaned by making the spin faster until coarse grains leave; finer desired grains may already be leaving. A very fine fraction may need lower ejection intensity even when coarse feed benefits from stronger agitation.

## Repeatable next experiment

1. Clean the pocket/catcher and retain the present concentrate and tailings separately. Record P07 presence. Confirm the marked shaft and bowl move together; actual RPM and pulse timing remain unmeasured.
2. Use mode 3 with its new doubled agitation first. This compares the requested duration change at the successful spin speed before introducing a speed increase. Use the lid for operation and stop before inspection.
3. Feed prewetted, dispersed material in measured **0.1–0.25 mL damp-settled increments** as an initial dosing experiment, preferably while stopped, then run a complete batch. This is not a calibrated throughput recommendation. Start smaller for the reported 98%-heavy material. For later continuous-feed trials, meter slowly only during agitation and pause feed before settle/spin; firmware does not control a feeder.
4. Collect discharge from each increment separately. Record remaining bed depth after settling/stopping. At 0.5 mL retained bed, clean out and measure; test a larger threshold separately, up to the provisional 1 mL ceiling only if acceptable. If losses occur below that, lower the threshold and investigate motion/water/size.
5. Compare equal classified samples in modes 3, 4, 5 and 6, each starting with a clean pocket and matching water delivery and fill. Increasing the mode on an already filling sample confounds speed with loading. Longer agitation increases total water delivery with unchanged burst schedules, so measure collected water over complete batches again.
6. Count known tracer grains or measure the desired heavy component in both retained product and all tailings. `recovery = desired material retained / desired material fed`; `grade = desired material retained / total concentrate`. Recover residue from walls/catcher and account for it separately in the mass balance. A second gentle recovery pass on tailings is useful, but is not proof that the first pass lost nothing.
7. Record the first bed depth at which target losses worsen. Repeat to establish an empirical cleanup threshold below that depth for each size fraction and mode. More jitter may allow rearrangement, but may also re-suspend fines; inspect the full tradeoff.

Stop feeding/clean out when the retained bed reaches the trial threshold, mounds toward the slope, stops rearranging, obstructs wash flow, or produces increased target losses. There is no level sensor or automatic overload response.

## Geometry decision

Keep the current bowl for controlled trials: the observed concentration is encouraging, and geometry cannot be diagnosed from a single stopped photo. If a fresh, shallow, classified sample still loses fines at mode 3 while coarse lights remain, decouple agitation from spin during a later experiment (strong rocking with less ejection), and test wash placement. If failures appear only at increasing bed depth, shorten the cleanup interval. A larger pocket, retaining lip or fluidization inlet is a separate geometry experiment with possible compaction, trapping and fine-loss tradeoffs. No geometry change is included in this firmware revision.

## Research references and limits

[1] [FLS gravity concentration product descriptions](https://fls.com/en/equipment/precious-metal-recovery/gravity-concentration): manufacturer distinguishes semi-continuous and continuous concentrate-stream designs. No capacity or G-force rating transferred to this printed bowl.

[2] [Sargent and Subasinghe, Selecting optimal operating conditions for Knelson Concentrators (2006), author university abstract](https://researchportal.murdoch.edu.au/esploro/outputs/conferencePaper/Selecting-optimal-operating-conditions-for-Knelson/991005542261207891): synthetic-mixture experiments, bed porosity, finite heavy accumulation and cycle-time dependence. Abstract reviewed, not full paper.

[3] [Characterisation and Modelling of Gravity Pre-Concentration Amenability Using LST Fluidisation in a REFLUX Classifier, Minerals 10 (2020), 545](https://doi.org/10.3390/min10060545): primary experimental/modeling study; indexed text reviewed (publisher page rate-limited). Supports particle-size dependence, not a numerical operating prescription for this bowl.

[4] [Gold recovery by KC from grinding circuit of Bergama CIP plant](https://www.scielo.br/j/rem/a/hsVX5hDh9K3TwtLXm5KPrPs/): primary plant study; indexed abstract/text reviewed (full-page retrieval failed). Reports fine-gold displacement associated with coarse gangue/heavy particles in a different concentrator geometry.

All numerical fill targets and screen bins above are proposed experiments. There is no CFD/DEM model, calibrated mineral identification, measured mass balance, or validated maximum load for this prototype. The CAD integration establishes geometric volume only.

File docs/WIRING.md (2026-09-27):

# Wiring: ESP8266 NodeMCU + assumed A4988 + bipolar stepper

The photograph clearly reads ESP-12E / ESP8266MOD. Use the NodeMCU D-labels below, not pin positions counted from a photo. The driver chip cannot be read under the heatsink; **verify A4988 and the carrier labels before using this wiring**. The schematic is logical, not a physical pin-layout drawing. Do not infer carrier orientation from potentiometer location or PCB color.

Wiring

## 12 V input and 5 V breadboard rail

The L7805 is a **fixed 5 V linear voltage regulator IC**, not a discrete power transistor. The heatsink hides the marking in the new photos, so “L7805CD” is not a verified part number. These instructions assume a genuine **L7805CV / L7805 in TO-220**: confirm the complete marking and manufacturer pinout before power. Do not use this pin order for an unidentified device or another package.

12 V to 5 V power and breadboard rails

With the breadboard oriented as in the photos (NodeMCU USB at left), assign **upper red = +5 V**, **lower red = +12 V**, and **both blue = common GND**. The short jumpers near VIN appear to reach the upper rails; remove and meter them before reuse. A red stripe does not establish voltage. Do not copy hole numbers from these photos: header labels and underside connections are not all visible.

| Connection | Destination / placement |
|---|---|
| Regulated 12 V supply + | Fused distribution point; separate secure branches to driver VMOT, pump branch and lower +12 V rail |
| Supply − | Common ground distribution; separate motor/pump return wires and breadboard ground branch |
| L7805 pin 1, INPUT | Lower +12 V rail |
| L7805 pin 2, GND | Common GND; bare TO-220 metal tab is also GND |
| L7805 pin 3, OUTPUT | Upper +5 V rail |
| Upper +5 V rail | Verified NodeMCU VIN (sometimes abbreviated VN), never 3V3 |
| Both blue rails | Join together and to supply −, NodeMCU GND, regulator GND and driver logic GND |
| 330 nF (0.33 µF) ceramic, ≥25 V | INPUT to GND, directly beside regulator pins |
| 100 nF (0.1 µF) ceramic, ≥16 V | OUTPUT to GND, directly beside regulator pins |
| 10 µF electrolytic, ≥16 V | + to 5 V, − to GND near VIN; additional local bulk |
| 1k ohm, ≥0.25 W resistor | 5 V to GND; approximately 5 mA minimum load for standalone regulation checks |
| NodeMCU 3V3 | Driver VDD, MS1/MS2/MS3, RESET/SLEEP and EN pull-up, as above |

**Regulator orientation:** with the flat printed face toward you and leads pointing down, verified ST TO-220 L7805 pins run left-to-right **1 INPUT, 2 GND, 3 OUTPUT**. Viewed from the metal back, left/right reverse. Put the three leads in three electrically separate breadboard strips. Keep its grounded tab/heatsink clear of the driver, positive rails and exposed pins.

Long breadboard rails may be split in the middle. With all power disconnected, check continuity end-to-end and bridge each split only to the same net: 5 V to 5 V, 12 V to 12 V, GND to GND. **Never bridge the two positive rails.** Check that each module straddles the center trench correctly and that no breadboard contact strip shorts opposite header pins. Use header extenders if the wide NodeMCU blocks access.

Motor VMOT and pump current must use short secure soldered/terminal wiring from the supply distribution point, including their returns. The lower breadboard 12 V rail only supplies the regulator branch. Retain the separate 100 µF / 25 V capacitors at VMOT and the pump circuit. Select supply capacity and branch fuses from measured combined operating/startup currents and wire ratings.

### Heat and USB power

The regulator dissipates approximately `(12 − 5) × I` watts plus its own operating loss: **0.7 W at 100 mA, 1.4 W at 200 mA, 2.1 W at 300 mA**. These are examples, not measured board current. The photographed heatsink must be tested under sustained load; a headline 1–1.5 A rating does not establish usable current at this voltage drop. Keep the hot assembly above the plastic. If voltage sags, the MCU resets or thermal shutdown occurs, stop and improve cooling or use a suitable 12-to-5 V buck converter.

**Use only one NodeMCU power source at a time.** For upload/USB Serial Monitor: switch off 12 V, disconnect the regulator's 5 V-to-VIN lead, then plug in USB. Leave VIN disconnected throughout USB use, even when restoring 12 V to test the driver/pump. Unplug USB before reconnecting VIN. Turning off 12 V alone does not prevent USB from backfeeding the external regulator on some clones. The exact board power-isolation circuit is unverified.

### Before connecting the NodeMCU

1. Disconnect USB, NodeMCU VIN, motor and pump power branches. Check rail isolation, regulator pin identity and capacitor polarity with power off.
2. Power the regulator branch from current-limited 12 V with its 1k load installed. Measure about 12 V on the lower positive rail and about 5 V on the upper positive rail, each against common GND. If output is not near 5 V, disconnect and diagnose before attaching the board.
3. Switch off, connect the verified VIN and GND, then power up. Confirm about 5 V at VIN and about 3.3 V at 3V3. Check stability and regulator temperature during sustained operation.
4. Switch off before adding the verified driver and motor wiring. Set the current limit and test empty-bowl LOW first. Add the protected pump branch last and check both rails during startup. A multimeter may miss brief transients; investigate resets or dips before continuing.

## Driver signals and power

| A4988 terminal | Connect to |
|---|---|
| STEP | NodeMCU D5 / GPIO14 |
| DIR | NodeMCU D6 / GPIO12 |
| EN / ENABLE | NodeMCU D7 / GPIO13; also 10k resistor to 3V3 |
| VDD | NodeMCU 3V3 |
| Logic GND | NodeMCU GND |
| MS1, MS2, MS3 | Each to 3V3, selecting 1/16 microsteps on A4988 |
| RESET and SLEEP | Tie together AND connect to 3V3; do not leave RESET floating |
| VMOT | Regulated +12 V distribution point, through secure wiring (not breadboard rails) |
| Motor-power GND | Motor supply negative; join logic/NodeMCU ground |
| 1A, 1B | The two wires of one motor coil |
| 2A, 2B | The two wires of the other motor coil |

Add a **100 µF electrolytic capacitor rated at least 25 V for a 12 V supply** directly between VMOT (+) and motor GND (-), with short leads and correct polarity. Pololu specifies at least 47 µF to reduce LC spikes; 100 µF is the chosen starting value. Use an appropriately higher voltage rating for any higher supply. Do not distribute motor coil current through thin solderless-breadboard power rails; use short, secure motor/power connections and a soldered carrier/header arrangement. Keep motor wiring away from the button line.

Power NodeMCU VIN from the L7805 regulated 5 V rail described below. Do not put 12 V on its 3V3, USB, GPIO or VIN pins. All grounds share a reference. Avoid D3/GPIO0, D4/GPIO2 and D8/GPIO15 for these external signals because of ESP8266 boot strapping. D4 may drive the onboard LED internally.

The external EN pull-up keeps the driver disabled while the MCU boots or resets. Firmware alone cannot control a floating pin during reset. If logic power is absent, do not assume the GPIO can keep the driver disabled; use the motor supply disconnect when working on wiring.

## Button

Use a normally-open button between **D2 / GPIO4 and GND**. The internal pull-up is enabled; no external resistor is necessary for short local wiring. Four-leg tactile switches have two internally connected pairs. With power off, use continuity mode to find two pins that connect only when pressed. A same-side pair may be permanently shorted, so do not choose pins by appearance. Disconnect the pictured OLED during initial setup; its pinout and controller are not established and it is not used by this firmware.

## Motor coil identification and current limit

Disconnect all power before changing motor connections. Never unplug the motor while the driver is energized.

Use an ohmmeter to find the two independent pairs with winding resistance. Wire one pair to 1A/1B and the other to 2A/2B. Do not trust motor wire colors. Swapping the two wires within one coil reverses rotation, or use the software direction flag. The photo does not establish the motor's connector pinout.

For a verified A4988, the nominal current-limit equation is `I_limit = VREF / (8 * Rsense)`. Read the actual sense resistor value on your carrier. Examples: R050 means 0.050 ohm, R100 means 0.100 ohm. For illustration only, a 0.50 A limit gives VREF = 0.20 V with R050, or 0.40 V with R100. These are not a recommended rating for this unidentified motor/clone. Choose a limit no higher than the motor's verified phase rating and the carrier's thermal capability. Follow the carrier manufacturer's adjustment procedure; a slip of the probe or screwdriver can short adjacent pads.

Firmware cannot adjust A4988 current through STEP/DIR. Supply current is not the same as winding current. The heatsink alone does not establish continuous-current capability; ensure it cannot short exposed pins and check cooling. Coils remain enabled during running settle/rest periods; they are disabled after a stop.

## Peristaltic water pump

D1 / GPIO5 now controls the 12 V Kamoer NKP-DC-S10B through an IRF9540N P-channel high-side MOSFET driven by a 2N3904 NPN (4.7k base, 100k base pulldown, 10k gate-source pull-up and 1k collector-to-gate resistors). Follow the complete [pump connections, protection and calibration guide](PUMP.md). Never connect the pump directly to a GPIO.

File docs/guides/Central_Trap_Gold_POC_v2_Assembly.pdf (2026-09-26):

ASSEMBLY GUIDE / SEPTEMBER 2026

# Central Trap / compact v2

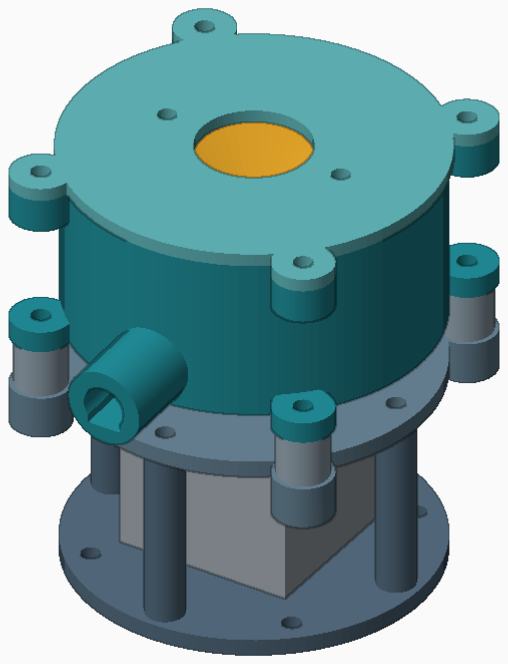
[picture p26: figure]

64 mm bowl | Experimental separator | Dimensions in mm | 01

## HALF-SIZE BOWL

### 64 mm diameter, reduced from 128 mm. Approximate assembled envelope: 86 x 103 x 104 mm, including the

drain.

A small, modular experiment for central collection of fine heavy particles. Full-size M4 hardware and the NEMA17 motor are retained.

Read before printing
Check motor dimensions and insert fit on pages 3-4. This revision has analytical screening and CAD checks, not CFD or demonstrated gold recovery.

Blue arrows show assembly motion. Gold parts rotate. Teal parts catch water. Rendered screws are replaced by fastener maps and size labels.

# Printed parts / one small kit

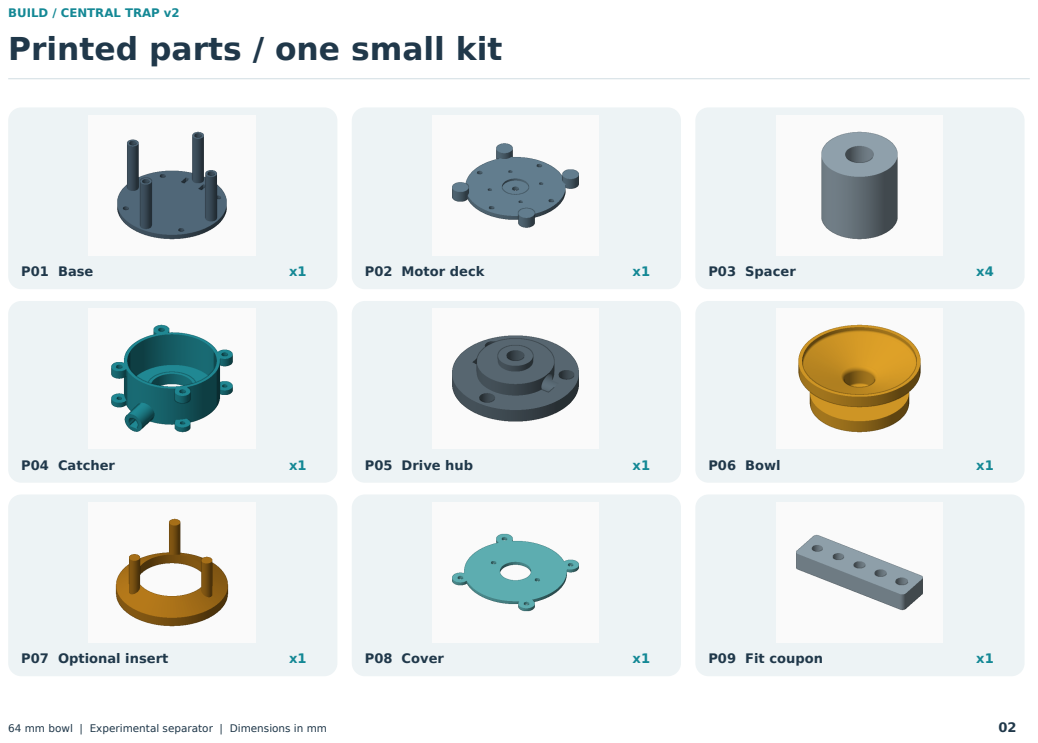
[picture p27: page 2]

# Hardware / keep these sizes full-size

M4 heat-set inserts | 17 | About 6 OD x 6 long; test coupon first
M4 x 10 socket screws | 4 | Motor deck to base
M4 x 25 socket screws | 4 | Catcher through spacers into deck
M4 x 8 socket screws | 7 | 3 hub-to-bowl + 4 cover
M4 x 10 flat-point set screws | 2 | Opposed motor-shaft locking screws
M3 x 8 socket screws | 4 | Motor mounting; verify thread depth
F5-10M / F5-10G thrust bearing | 1 | 5 bore x 10 OD x 4 overall
5 mm shaft NEMA17 motor | 1 | Body/mounting assumptions listed below
Drain hose + feed tubes | - | 18 mm ID drain; 4 mm OD feed tubes

Motor fit assumption: 42 mm square body, 40 mm body length, 31 mm mounting-hole square, 22 mm pilot no more than 2 mm high. Shaft projection above the mounting face must be about 18-26 mm. A 5 mm shaft alone does not verify these dimensions.

Also needed: matching hex keys, soldering iron with insert tip, calipers, cable ties, a secondary spill tray, and a current-limited stepper driver/controller. Exact motor current and pinout remain unverified. Do not guess wire pairs or driver current.

# Prepare / test the inserts before the full print

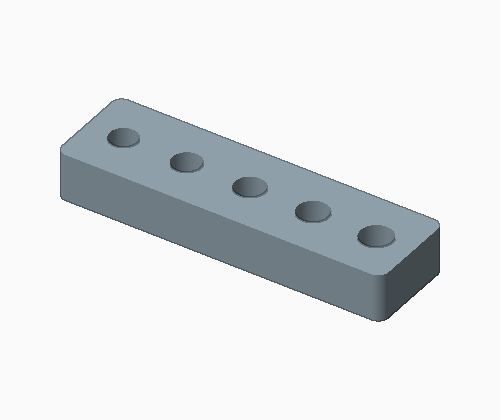
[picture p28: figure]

5.2 | 5.4 | 5.6 | 5.8 | 6.0

Coupon holes increase in diameter from the small-hole end. Measure to identify them; this view is illustrative. All assembly insert holes are nominally 5.6 mm.

Press one insert squarely into the coupon. Let it cool, then test a screw. The insert must hold without cracking or spinning. If another hole size fits better, change INS in build_v2.py and regenerate the parts; do not scale the STL.

### INSERT MAP

P01 base

4 / upper ends of posts

P02 deck

4 / outer bosses, from above

P04 catcher

4 / upper cover bosses

P05 hub

2 / opposite radial holes

P06 bowl

3 / blind underside holes

Seat inserts flush. Keep heat away from bearing seats and the bowl floor. Never drill the bowl holes through into the wet chamber.

Before printing: verify motor body, pilot, hole pitch and shaft projection. Unknown motor and insert dimensions are fit assumptions, not measured facts.

# 01 Attach the motor to its deck

ADD | P02 + motor
| 4 x M3 x 8 socket screws

A
Face the motor shaft upward. Put the motor pilot into the recess on the underside of P02.
B
Install four M3 screws from above the deck. Tighten evenly. Use shorter screws if the motor thread depth is insufficient.

FASTENER POSITIONS

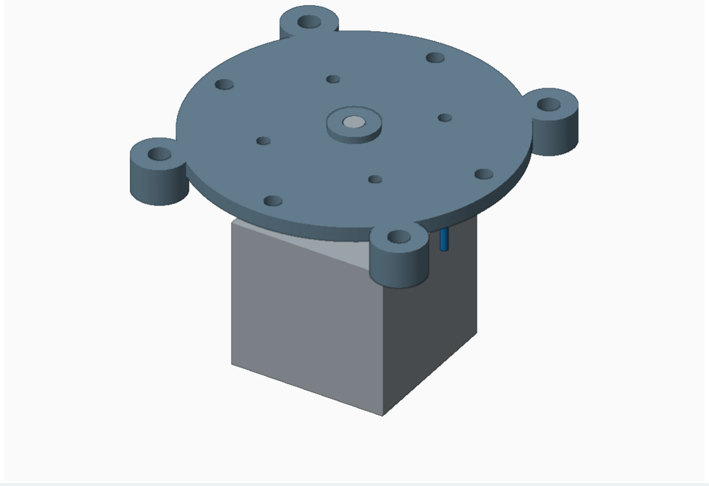
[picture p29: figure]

CHECK Motor face sits flat. Shaft passes freely through the 5.6 mm opening.

# 02 Lower the motor into the base

ADD | P01 + motor/deck assembly
| 4 x M4 x 10 socket screws

A
Lower the motor between the four base posts. Align the four inner deck holes with the post inserts.
B
Run the cable out through an open side. Tie it to the two base slots, clear of the shaft and drain side.
C
Install the four M4 screws. Secure the base to the bench through its spare mounting holes.

FASTENER POSITIONS

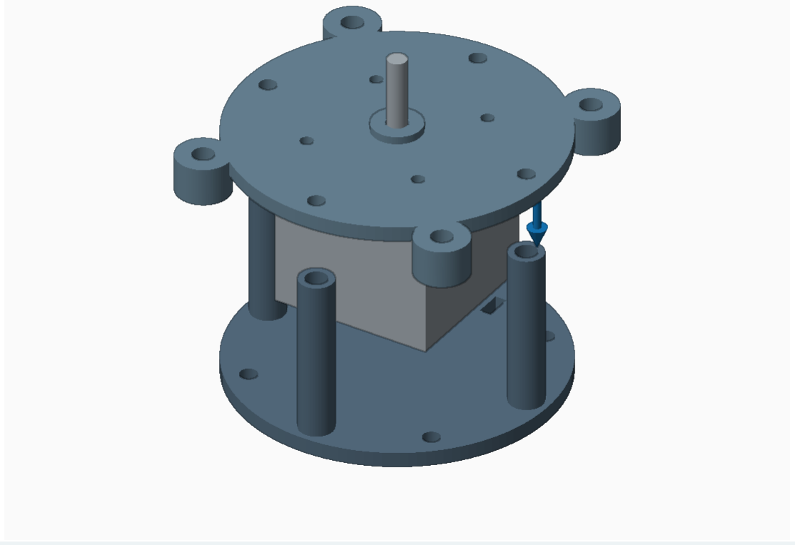
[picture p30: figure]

CHECK Motor clears the base floor; wires are not pinched.

# 03 Stack the thrust bearing

ADD | 1 x complete 5 x 10 x 4 thrust bearing
| No screws in this step

A
Slide the lower housing washer onto the central pedestal, followed by the ball cage and upper shaft washer.
B
Bearing grooves face the balls. Use the bearing maker's orientation; the housing washer typically has the slightly larger bore.
C
The upper washer turns with the hub. This bearing carries axial load; the motor still guides the rotor radially.

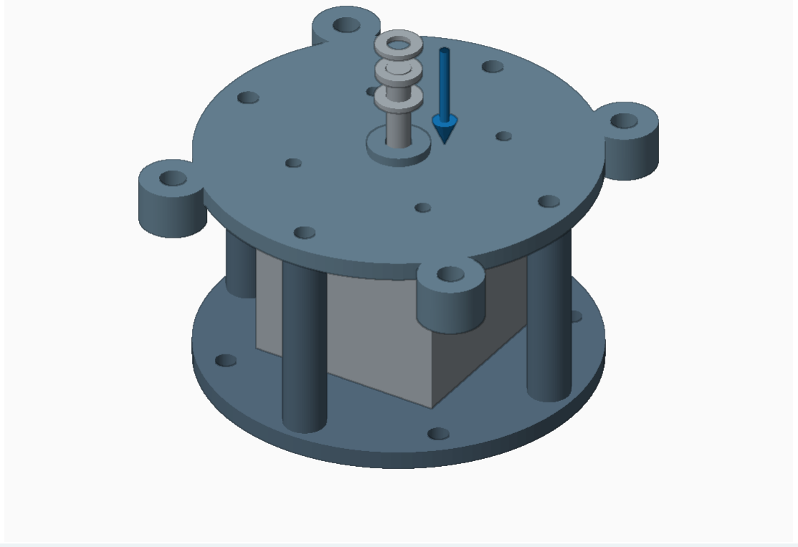
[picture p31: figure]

CHECK Bearing stack sits flat on the pedestal and turns freely.

# 04 Build the rotor outside the machine

ADD | P05 hub + P06 bowl
| 3 x M4 x 8 socket screws; 2 x M4 x 10 set screws

A
Align the three hub flange holes with the three dry inserts under the bowl. B
Insert the three M4 x 8 screws from below the hub flange. Tighten evenly without distorting the bowl.
C
Start both radial set screws in the hub. Back them out until the shaft bore is unobstructed.

FASTENER POSITIONS

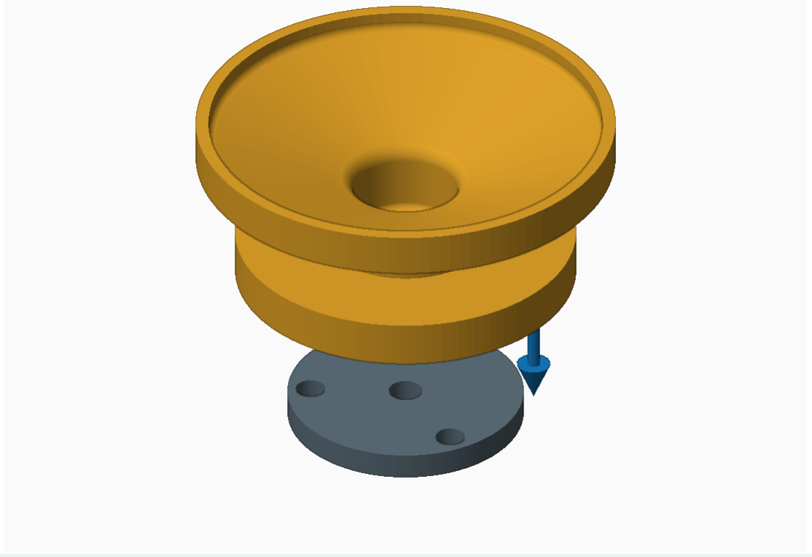
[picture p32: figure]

CHECK No screw enters the water chamber. Keep this rotor aside for step 7.

# 05 Set the four spacers

ADD | 4 x P03 spacers
| No screws yet

A
Place one 12 mm spacer on each of the four outer deck bosses.
B
Align the spacer holes with the inserts below. Keep the bearing and motor shaft clean.

FASTENER POSITIONS

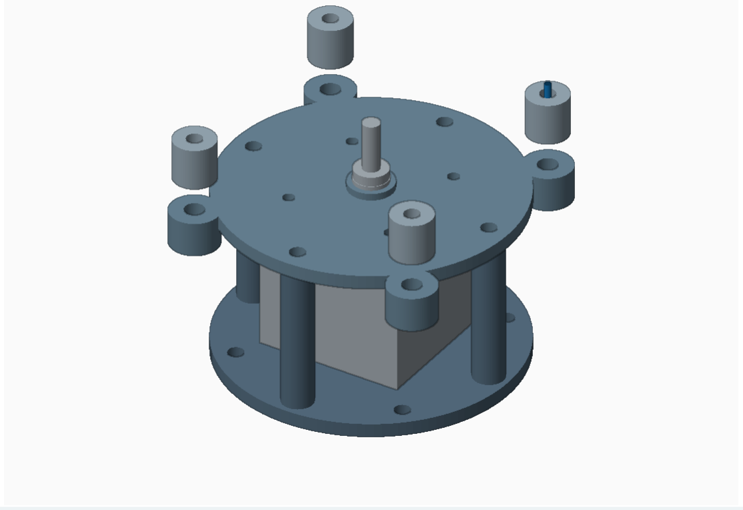
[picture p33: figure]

CHECK All four spacers sit upright and flat.

# 06 Mount the catcher

ADD | P04 catcher
| 4 x M4 x 25 socket screws

A
Lower the catcher onto the four spacers. Point the drain toward your collection hose.
B
Pass each screw through a lower catcher tab and spacer into a deck insert. Tighten in alternating pairs. C
The large central opening stays open for installation of the rotor. Keep the upper cover inserts empty.

FASTENER POSITIONS

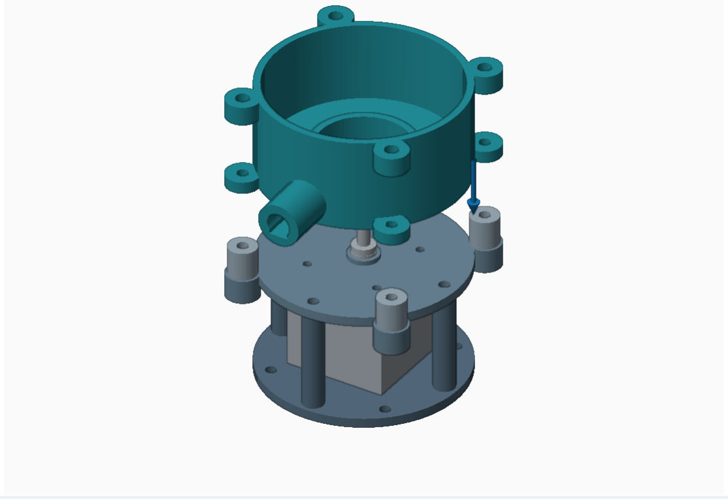
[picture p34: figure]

CHECK Four spacers are trapped squarely. The catcher is stationary.

# 07 Seat and lock the rotor

ADD | Preassembled P05 + P06 rotor
| Tighten the 2 opposed M4 set screws

A
Lower the rotor onto the 5 mm shaft. Its hub nose rests on the upper thrust-bearing washer.
B
Reach the two set screws through the gap below the catcher. Tighten evenly with a straight hex key; do not force axial preload.
C
Turn the bowl by hand through a full revolution. Stop if it rubs, rocks or binds. Adjust fit before powering.

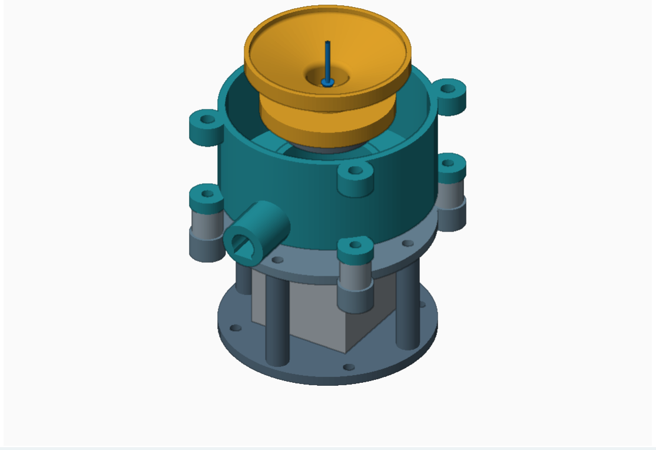
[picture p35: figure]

CHECK Nominal skirt clearance: 1.3 mm radial, 1 mm vertical. Real print runout must fit inside it.

# 08 Fit the cover and water lines

ADD | P08 cover + hose + feed tube
| 4 x M4 x 8 socket screws

A
Install the cover on the four upper catcher bosses. Tighten the four screws lightly and evenly.
B
Secure feed tubing in the 4.3 mm ports. Keep tube ends at least 3 mm above the highest bowl rim; stop them from sliding downward.
C
Connect a drain hose to the 18 mm OD spout. Support the hose so it cannot twist the printed spout.

FASTENER POSITIONS

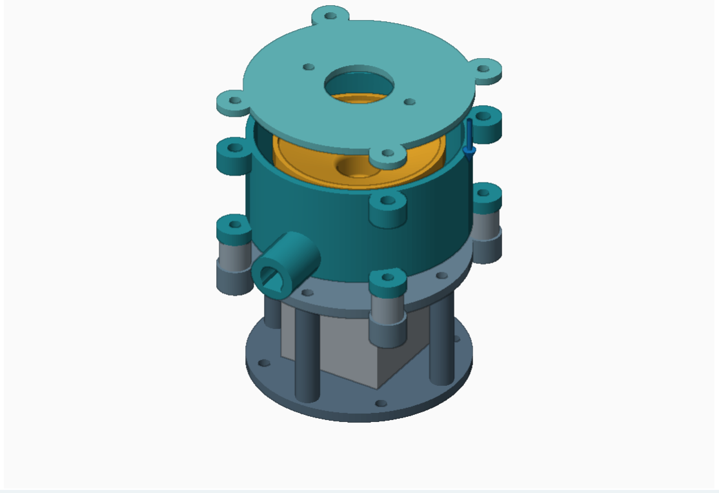
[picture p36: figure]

CHECK Feed opening is 26 mm. The lid is a splash cover, not a sealed pressure lid.

# Water path / floor-level drain

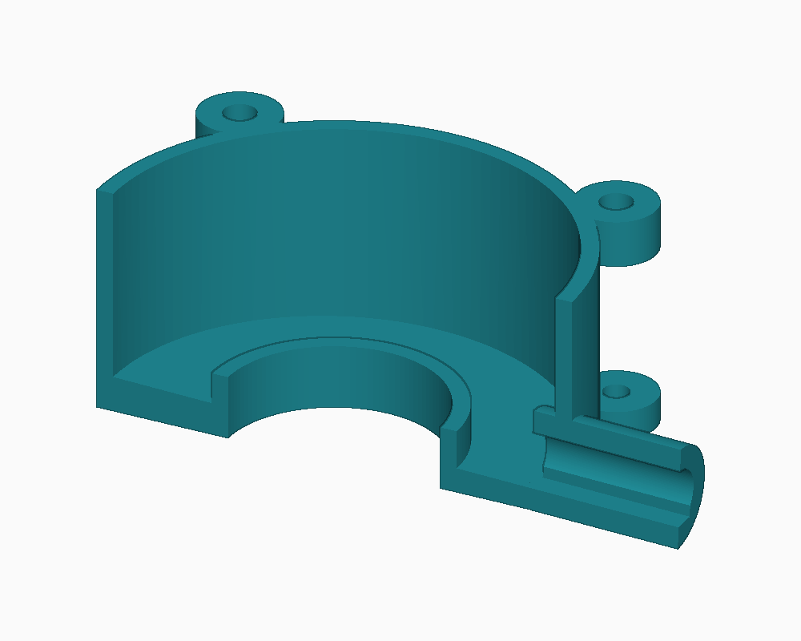
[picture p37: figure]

SECTION THROUGH CATCHER

1 / Overflow
Water passes over the bowl rim into the stationary catcher. The rotating bowl itself has a continuous wet wall and floor.

2 / Sloped floor
The catcher floor falls 3% toward the drain. The flat-bottomed outlet follows that slope, with no designed raised sill.

3 / Downhill outlet
Run the hose continuously downhill into a second container. A blocked outlet can flood the central shaft opening and motor.

Leak-test bowl and catcher separately before assembly. Closed STL geometry does not make an FDM print watertight. Inspect seams and coat/reprint if needed.

# Central sump / start without the optional insert

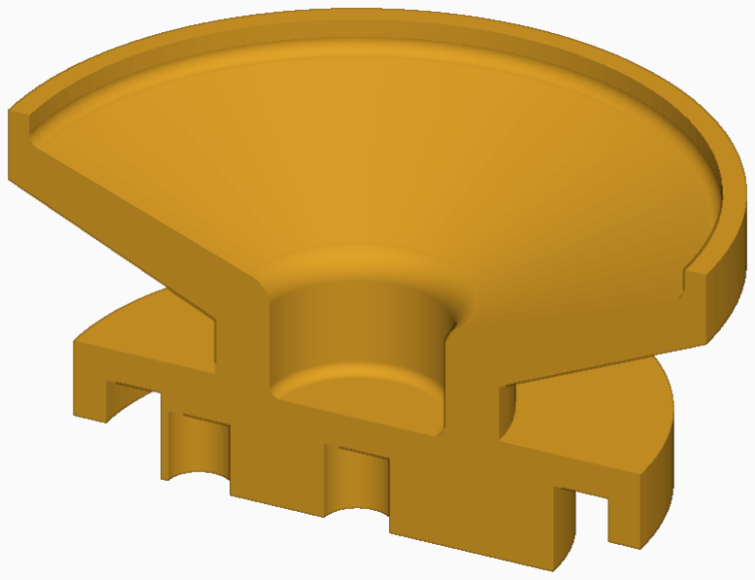
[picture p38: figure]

Open sump - first test
The 16 mm sump has a smooth rounded entrance and roughly 1.7 mL of deep pocket volume. There is no raised collar across the working slope. The slope may help migration only when grains can actually slip or be mobilized.

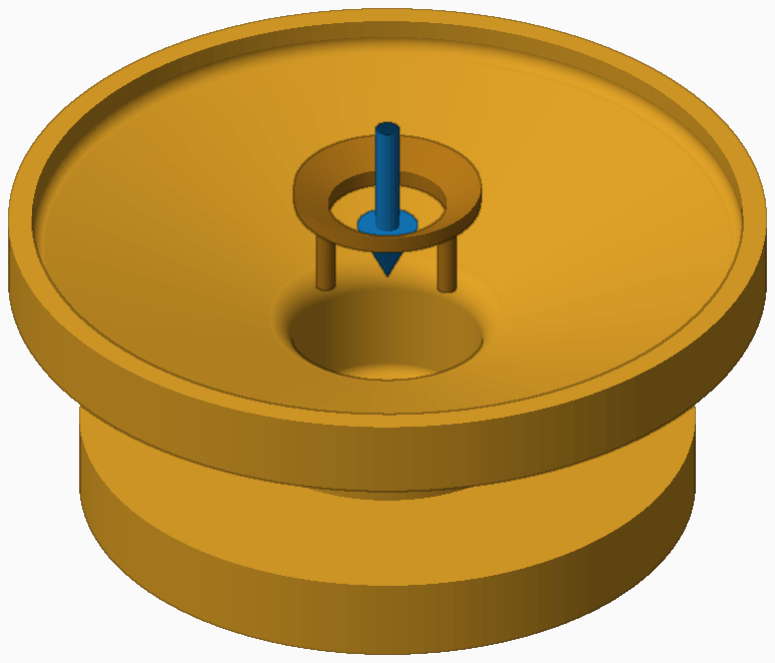
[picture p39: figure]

P07 - later A/B test only
Three feet rest on the sump floor. The cone remains below the entrance; its central opening is 10 mm. It is gravity-seated, not locked. Omit it if warped, loose or lifting during a test.

A pocket can trap sand and clay as well as gold. This is not a one-way valve and cannot guarantee that fine gold stays in. Inspect and clean it frequently.

# Printing / use the delivered orientations

STLs are in millimeters and already oriented for printing. Print one of each file, except P03: print four. Do not apply 50% scaling in the slicer; the redesign is already reduced.

P01 | Base down | Brim helps tall posts; keep post bores clean
P02 | Deck inverted | Support broad deck face around the 2 mm bearing pedestal
P03 | Spacer upright | No support normally needed
P04 | Catcher upright | Support spout, lower body and projecting upper bosses
P05 | Flange down | Keep shaft bore and radial insert bores clear
P06 | Bowl upright | Support external flare and underside skirt; protect wet face
P07 | Cone inverted | Fine layers; delicate legs; experimental part
P08 | Cover flat | No support normally needed
P09 | Coupon flat | Print first using the intended final material/settings

Starting settings: PETG, 0.20 mm layers, 5-6 perimeters, 6-8 top/bottom layers, 40-60% infill. Use 0.12-0.16 mm layers for P07. These are starting points, not a waterproofing certification. Remove supports and strings; keep paired rotating hardware equal.

# Commission / measure losses before adding more feed

A DRY FIT
Hand-turn a full revolution. Check shaft grip, bearing seating, cover clearance and cable routing. Keep a spill tray underneath.

B WATER ONLY
Start with small oscillations, about +/-3 to 5 degrees at 0.5-1 Hz. Use smooth acceleration. Check leakage and rubbing. These are exploratory commands, not a motor rating.

C SMALL SAMPLE
Wet-screen and disperse clay. Begin with 0.5-2 g of screened sand, not a full hopper. Try 5-30 mL/min water after filling, then adjust to obtain gentle overflow. Stop if material packs or the drain backs up.

D KEEP EVERY TAILING
Use separate containers for overflow and final concentrate. Rinse and inspect both. Test with known-size gold only after mechanical tests; quantify losses by size class.

E CHANGE ONE VARIABLE
Compare open sump to optional insert; record water, frequency, angle, sample mass and run time. Delay any spin/ejection experiments until baseline recovery is measured.

No unattended continuous-feed claim: capacity, clay handling, recovery and safe motor settings are unproven. Never discard test tailings. No controller or automatic feeder is included.

# Mechanics / what has and has not been modeled

ANALYTICAL SCREENING

The working slope is approximately 20.2 degrees. Rotation produces outward acceleration a = omega squared x radius. At 30 rpm and a 29 mm radius, this is about 0.029 g. Faster spinning increasingly opposes travel toward the center.

A simplified particle sliding down a rotating cone requires: omega squared x r / g < (tan(beta) - mu) / (1 + mu tan(beta)) Here mu is sliding friction. The ideal dry-contact model omits drag, bed interactions and transient water motion. Density cancels: this is not a gold-selection rule.

Calculated inward-sliding limits at 29 mm radius:
mu = 0: 107 rpm; 0.1: 89 rpm;
0.2: 70 rpm; 0.3: 44 rpm.
At mu = 0.4, the model predicts no spontaneous inward sliding even at rest. These are not operating speed limits.

FINE PARTICLES NEED TIME

Stokes settling gives v = (rho particle - rho water) g d squared / (18 viscosity). A spherical 10 micrometer gold grain in clean water needs roughly 5 seconds to fall 5 mm; a 20 micrometer sphere needs about 1.25 seconds.

At five times the viscosity, those times become about 25 and 6.3 seconds. Real clay slurry may be non-Newtonian; gold flakes, attached clay and a moving particle bed are outside this simple model.

Published tea-leaf-paradox studies support possible inward near-bottom transport under some rotating-flow conditions. They also show sensitivity to geometry and confinement. They do not establish this device as a gold concentrator.

No CFD, particle-transport simulation or bench recovery test was performed. Bowl angle and sump geometry are testable choices, not an identified optimum or a guarantee.

# Review record / references and revision notes

GEOMETRY REVIEW

All 9 STLs were rendered and visually reviewed from top-oblique, underside-oblique and front views. The bowl and catcher were also sectioned. The package includes these review sheets.

Every exported STL passed closed-edge, consistent-orientation and positive-volume checks. All CAD parts are valid single solids. The modeled assembly has no detected interference; the rotor was checked every 15 degrees. This does not measure print tolerance, physical balance or recovery.

Changed from v1: 64 mm bowl; shorter direct-shaft drive with a thrust bearing; round mounting bosses; sloped catcher floor and floor-level D-shaped drain; smooth open sump entry; optional recessed insert. The 18 mm hose connection and M4 hardware remain full-size.

PRIMARY REFERENCES

1. Rotating-flow / bottom inclination study, Micromachines 14(11), article 2024 (2023).
Open primary source (https://www.mdpi.com/2072-666X/14/11/2024)
2. Stepper-driven cup / particle aggregation study, volume 4(3), article 37 (2024).
Open primary source (https://www.mdpi.com/2673-8716/4/3/37)
3. SMB Bearings: F5-10G dimension drawing (5 x 10 x 4 mm). Open primary source (https://www.smbbearings.com/firebrick/ckeditor/plugins/upload/Uploads/Documents/bearingpdfs/F5-10G-thrust-bearing-5x10x4mm.pdf)
4. US EPA: gravity concentration, feed preparation and recovery context.
Open primary source (https://www.epa.gov/international-cooperation/artisanal-and-small-scale-gold-mining-without-mercury)

Sources explain mechanisms and hardware dimensions. None validates this prototype. Exact Moons C17HD40-102-0 1N ratings were not verified.

Files: STL print parts; STEP geometry; assembly.step; build_v2.py; check reports; multi-view review sheets. Re-run the generator after changing motor or insert dimensions.

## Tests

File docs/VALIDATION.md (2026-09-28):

# Validation record

## Corrected straight-post base

The angled-post revision is superseded. Current base has four straight vertical post axes at diagonal positions; existing P02 must receive four new clearance holes. Motor, drilled-deck and four assumed connector-envelope intersections are checked by the generator. STL topology and rendered views are checked. No physical strength/fit test is implied. See the current base `checks.json`; old interim triangle counts and interface claims no longer apply.

## Current pump/lid revision

2026-09-26: ESP8266 build passed, RAM 28,844 / 81,920 bytes, flash 273,491 / 1,044,464 bytes. All 15 host tests passed (8 motion/button tests plus 7 pump tests). Pump tests cover phase gating, timing across reversals, preset intervals, cancellation, manual run limits, rollover and delayed loops. Lid is one valid solid with a closed oriented 17,854-triangle mesh. Modeled lid/brass/screw clearances against the original bowl and catcher passed. Multiple exported-mesh views and a section were visually reviewed. Pump wiring was rendered and visually reviewed.

Flow, leakage, startup current, thermal behavior and recovery remain unmeasured. This repository archival/documentation update changes no firmware or geometry. Preserved artifact bytes are indexed in `ARTIFACT_MANIFEST.json`.

## Original firmware baseline

2026-09-26, PlatformIO Core 6.2.0, Linux host.

- `pio run -e nodemcuv2`: PASS. Espressif8266 platform 4.2.1, Arduino core 3.1.2, AccelStepper 1.64.0. RAM 28,712 / 81,920 bytes (35.0%); flash 272,919 / 1,044,464 bytes (26.1%). Firmware binary linked successfully.
- `pio test -e native`: PASS, 8 cases. Boot idle, queued mode/sequence/spin distance, controlled and immediate stop, every normal stop phase, button click/hold, boot-held suppression, bounce/timer rollover, and 1,000 repeated batches with position rebasing.
- The same control tests also compiled with host GCC using `-Wall -Wextra -Werror` and passed.
- Wiring SVG rendered and visually reviewed.
- AccelStepper's enable-pin initialization behavior checked against source; registering the pin before selecting active-low polarity avoids an unintended LOW at startup.

Not performed: flashing the user's board, electrical identification of the covered driver, verifying the motor current rating, oscilloscope timing, physical motion/load/thermal tests, or gold recovery measurements. The firmware build and host tests do not replace those checks.

The first package mirror returned invalid downloads; PlatformIO rejected their checksums and obtained valid packages from another mirror. Verification was not bypassed. Framework elf2bin.py emitted Python invalid-escape SyntaxWarnings, but the binary build succeeded; CI uses Python 3.11.

## 2026-09-26: shared 12 V / L7805 documentation revision

Updated README, wiring guide, pump guide, hardware reference, standalone power/stepper/pump SVGs and combined diagram. Rendered all three standalone SVGs with Inkscape and visually checked labels and connections. XML parsing, generator repeatability and whitespace checks passed. Regenerate with `python tools/draw_wiring.py`; `docs/stepper_wiring.svg` is the editable stepper source. Existing mechanical PDF contains no integrated electronics diagram; original release archives remain historical snapshots. Firmware and CAD are unchanged; no new firmware test run is claimed.

Physical checks still required: obscured regulator marking/pinout, driver identity, clone VIN power path, breadboard continuity, output voltage under load, regulator cooling, current limit and motor/pump startup transients.

## Inventory-based pump switch (2026-09-27)

Replaced the AO3400A circuit with IRF9540N high-side switching, 2N3904 level shifting and a 1N5822 flyback diode using photographed stock. Verified reference manufacturer pinouts/ratings and calculated gate drive, base current and nominal conduction loss. Updated the standalone and combined diagrams, their generators, connection tables and firmware comments. Active-HIGH firmware behavior is unchanged. SVGs were XML-parsed, regenerated for repeatability and the pump PNG was visually inspected; git diff whitespace checks passed. No new firmware test or physical pump test is claimed.

Before operation, verify the actual kit components/pinouts, reset-OFF behavior, gate voltages, pump startup current and temperature using the procedure in PUMP.md.

## Loaded-bed motion revision (2026-09-27)

- PlatformIO native tests: 16/16 passed (9 control/button/envelope, 7 pump). Host GCC with `-Wall -Wextra -Werror` also passed both suites.
- Real AccelStepper 1.64 source, simulated clock/GPIO: all three modes reached their requested spin speed, completed the batch and matched approximate analytical period/burst duration within 50 ms. Recurring rocking frequencies 2.463/2.935/3.165 Hz; spin 1.077/1.081/1.084 s. This is a library command simulation, not measured board timing or mechanics. Added the check to CI.
- Compile-time requested-pulse-rate budget and regression checks reject 300 RPM / oversized rocking ceilings. Existing controlled stop, emergency release, mode queuing and pump gating tests remain passing.
- CAD P06 source profile inspected; no geometry changed. Documented loaded-sump limitations, research, calculations and controlled physical trials in MOTION.md; amended guide index so archived settings are not mistaken for current presets.
- No physical hardware, torque, missed-step, flow or recovery validation was performed.
- ESP8266 `pio run -e nodemcuv2`: PASS; RAM 28,844/81,920 bytes, flash 273,507/1,044,464 bytes. PlatformIO rejected invalid mirror checksums and used alternate downloads; no verification was bypassed. Framework elf2bin.py emitted Python escape-sequence warnings; firmware linked and BIN generation succeeded.

## Tripled trial after further physical feedback (2026-09-27)

Rocking speed ceilings and acceleration, spin RPM and spin acceleration are each 3× the preceding revision. Angle, count and dwell settings remain unchanged. Native tests 16/16 PASS; ESP8266 build PASS (RAM 28,844 bytes, flash 273,507 bytes). Real AccelStepper simulation PASS: recurring frequencies 4.601/5.592/6.067 Hz, spin durations 1.086/1.088/1.112 s, peak spin 90/135/180 RPM. Tests now handle triangular rocking profiles. Maximum requested rate 9600 pulses/s; selected budget 12000/s is unmeasured on hardware. No claim of physical tracking, available torque or improved gold recovery. Current README/MOTION amendment supersedes earlier preset tables and the former 60 RPM limit.

## Six modes, longer agitation and operating-capacity review (2026-09-27)

Operator reports previous mode 3 (180 RPM) gave strong visible central concentration and mud removal, with some heavies outside the bowl. The photo was inspected; identity, actual RPM, bed depth and recovery are not measured from it. New OPERATION.md records this evidence separately from hypotheses and proposed trial limits.

- Native tests: 18/18 PASS. Added six-mode wrap/invalid selection/queued mode-6 transition and all-six pump gating tests; verified doubled 36/48/60 cycle counts and pulse budget through mode 6. Existing stop/rollover/long-run tests pass.
- ESP8266 firmware build PASS: RAM 29,008/81,920 bytes, flash 273,671/1,044,464 bytes. Existing framework Python escape warnings only.
- Real AccelStepper 1.64 simulated-clock test PASS for all six profiles, including cycle counts and 7.5–11 second agitation bounds. Not a CPU-cost, torque or fluid model.

| Mode | Recurring Hz | Agitation through centering, seconds | Spin total seconds | Peak commanded RPM |
|---|---:|---:|---:|---:|
| 1 | 4.601 | 7.868 | 1.086 | 90 |
| 2 | 5.592 | 8.615 | 1.088 | 135 |
| 3 | 6.067 | 9.920 | 1.112 | 180 |
| 4 | 6.566 | 9.926 | 1.104 | 195 |
| 5 | 7.070 | 9.926 | 1.116 | 210 |
| 6 | 7.576 | 9.923 | 1.094 | 225 |

Static curved-cavity CAD reconstruction PASS: 0.9943 mL to 5 mm above floor, 2.2703 mL to slope entrance, 19.7254 mL to rim (without P07). These are geometry only; 0.5–1 mL cleanup targets are unvalidated conservative trial choices. Source and JSON are committed. No new mesh, physical mode-4–6 trial, pulse-trace measurement, continuous-feed capacity or gold mass balance is claimed. The existing software rate budget is 12000 pulses/s, now reached by mode 6; it is not a hardware throughput certification.

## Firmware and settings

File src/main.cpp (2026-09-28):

#include "Control.h"
#include "Pump.h"
#include <AccelStepper.h>
#include <Arduino.h>
#include <ESP8266WiFi.h>
// Do not initialize outputs from a global constructor before setup can drive EN high.
AccelStepper motor(AccelStepper::DRIVER, cfg::STEP_PIN, cfg::DIR_PIN, 0, 0, false);
Controller<AccelStepper> controller(motor);
Button button;
Pump pump;
void syncPump(uint32_t now) {
  pump.tick(now, controller.state(), controller.active());
  digitalWrite(cfg::PUMP_PIN, pump.on() ? HIGH : LOW);
}
void cancelPump() {
  pump.cancel();
  digitalWrite(cfg::PUMP_PIN, LOW);
}
bool reportPending = true;
void setup() {
  digitalWrite(cfg::PUMP_PIN, LOW);
  pinMode(cfg::PUMP_PIN, OUTPUT); // External 100k base pulldown + 10k gate-source pull-up hold OFF before setup.
  digitalWrite(cfg::ENABLE_PIN, HIGH);
  pinMode(cfg::ENABLE_PIN, OUTPUT);
  digitalWrite(cfg::STEP_PIN, LOW);
  pinMode(cfg::STEP_PIN, OUTPUT);
  digitalWrite(cfg::DIR_PIN, LOW);
  pinMode(cfg::DIR_PIN, OUTPUT);
  pinMode(cfg::BUTTON_PIN, INPUT_PULLUP);
  pinMode(LED_BUILTIN, OUTPUT);
  digitalWrite(LED_BUILTIN, HIGH);
  // setEnablePin writes HIGH with the default polarity, keeping A4988 off.
  motor.setEnablePin(cfg::ENABLE_PIN);
  motor.setPinsInverted(cfg::INVERT_DIRECTION, false, true); // Active-low A4988 EN.
  motor.setMinPulseWidth(3);
  motor.disableOutputs();
  WiFi.persistent(false);
  WiFi.mode(WIFI_OFF);
  WiFi.forceSleepBegin();
  Serial.begin(115200);
  Serial.println("\nGold separator: IDLE. Tap=mode; hold 0.8s=start/stop.");
  Serial.println("Serial: 1-6=mode s=start x=stop !=disable ?=status");
  Serial.println("Water: p=prime 3s c=calibrate 30s (idle only), w=auto toggle; x/! cancel");
}
void loop() {
  const uint32_t now = millis();
  const Phase before = controller.state();
  controller.tick(now);
  auto event = button.update(digitalRead(cfg::BUTTON_PIN) == LOW, now);
  if (event == ButtonEvent::Short) {
    controller.next();
    reportPending = true;
  }
  if (event == ButtonEvent::Long) {
    cancelPump();
    if (controller.running())
      controller.stop(now);
    else
      controller.start(now);
    reportPending = true;
  }
  // Bound serial work per iteration so input flooding cannot starve step generation.
  if (Serial.available()) {
    char ch = Serial.read();
    if (ch >= '1' && ch < '1' + cfg::PRESET_COUNT)
      controller.select(ch - '1');
    else if (ch == 's') {
      if (!controller.running()) {
        cancelPump();
        controller.start(now);
      }
    } else if (ch == 'x') {
      cancelPump();
      controller.stop(now);
    } else if (ch == '!') {
      cancelPump();
      controller.emergency(now);
    } else if (ch == 'p') {
      pump.dispense(now, cfg::PUMP_PRIME_MS, !controller.running());
    } else if (ch == 'c') {
      pump.dispense(now, cfg::PUMP_CALIBRATE_MS, !controller.running());
    } else if (ch == 'w') {
      pump.setAutomatic(!pump.automatic());
    }
    if (ch != '\r' && ch != '\n')
      reportPending = true;
  }
  const bool previousPump = pump.on();
  syncPump(millis());
  if (pump.on() != previousPump)
    reportPending = true;
  if (controller.state() != before)
    reportPending = true;
  // Defer formatting/transmission until rest; faster strokes need a tight run() cadence.
  if (reportPending && !motor.isRunning() && Serial.availableForWrite() >= 96) {
    char line[96];
    int n = snprintf(line, sizeof(line), "%s selected=%s active=%s water=%s auto=%u manual=%u\n",
                     phaseName(controller.state()), cfg::PRESETS[controller.selected()].name,
                     cfg::PRESETS[controller.active()].name, pump.on() ? "ON" : "OFF",
                     pump.automatic(), pump.manual());
    Serial.write(reinterpret_cast<const uint8_t *>(line), n);
    reportPending = false;
  }
  // 1-6 flashes per three seconds; distinct pause after the sixth flash.
  const uint32_t t = now % 3000;
  const bool flash = t < (controller.selected() + 1) * 300 && t % 300 < 120;
  digitalWrite(LED_BUILTIN, flash ? LOW : HIGH);
  controller.tick(millis());
  syncPump(millis());
  yield(); // ESP8266 watchdog; Wi-Fi disabled to reduce background timing jitter.
}

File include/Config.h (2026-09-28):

#pragma once
#include <stdint.h>
namespace cfg {
// Photo: ESP8266 ESP-12E NodeMCU, NOT ESP32. Use GPIO numbers here.
constexpr uint8_t STEP_PIN = 14, DIR_PIN = 12, ENABLE_PIN = 13, BUTTON_PIN = 4;
constexpr uint8_t PUMP_PIN = 5; // D1, active HIGH through 4.7k to 2N3904 driving IRF9540N high-side switch.
constexpr bool PUMP_AUTO_DEFAULT = true;
constexpr bool PUMP_DURING_SPIN = false; // Quiet settling and no added spin spray by default.
constexpr uint32_t PUMP_PRIME_MS = 3000, PUMP_CALIBRATE_MS = 30000;
struct PumpSchedule {
  uint32_t onMs, offMs;
};
constexpr PumpSchedule PUMP_SCHEDULE[] = {{500, 4500}, {750, 4250}, {1000, 4000},
                                            {1000, 4000}, {1000, 4000}, {1000, 4000}};
constexpr bool INVERT_DIRECTION = false;
constexpr unsigned FULL_STEPS = 200; // Assumed 1.8 degree motor; verify your motor.
constexpr unsigned MICROSTEPS = 16;  // A4988 MS1/MS2/MS3 all HIGH physically.
constexpr float STEPS_PER_DEGREE = FULL_STEPS * MICROSTEPS / 360.0f;
struct Preset {
  const char *name;
  float amplitudeDeg, speedDegS, accelDegS2;
  uint8_t cycles;
  uint32_t settleMs;
  float spinRpm, spinAccelDegS2, spinHoldSeconds;
  uint32_t restMs;
};
// Experimental loaded-bed trials; see docs/MOTION.md. Not motor ratings.
// Keep 1/16 wiring. Bound requested pulse rate for the cooperative step loop.
constexpr float MAX_STEP_RATE = 12000;
// Modes 1-3 keep the user's tested speeds and double the rocking cycle count.
// Modes 4-6 are modest experimental increments; same angle and ~10s agitation.
constexpr Preset PRESETS[] = {{"LOW", 12, 540, 7200, 36, 3000, 90, 1800, 0.5f, 2000},
                              {"MEDIUM", 16, 810, 14400, 48, 3000, 135, 2700, 0.5f, 2000},
                              {"HIGH", 20, 1080, 21600, 60, 3000, 180, 3600, 0.5f, 2000},
                              {"TRIAL4", 20, 1170, 25350, 65, 3000, 195, 3900, 0.5f, 2000},
                              {"TRIAL5", 20, 1260, 29400, 70, 3000, 210, 4200, 0.5f, 2000},
                              {"TRIAL6", 20, 1350, 33750, 75, 3000, 225, 4500, 0.5f, 2000}};
constexpr unsigned PRESET_COUNT = sizeof(PRESETS) / sizeof(PRESETS[0]);
static_assert(sizeof(PUMP_SCHEDULE) / sizeof(PUMP_SCHEDULE[0]) == PRESET_COUNT,
              "Pump preset mismatch");
constexpr bool validPump(PumpSchedule p) {
  return p.onMs > 0 && p.onMs <= 5000 && p.offMs > 0 && p.offMs <= 60000;
}
static_assert(validPump(PUMP_SCHEDULE[0]) && validPump(PUMP_SCHEDULE[1]) &&
                  validPump(PUMP_SCHEDULE[2]) && validPump(PUMP_SCHEDULE[3]) &&
                  validPump(PUMP_SCHEDULE[4]) && validPump(PUMP_SCHEDULE[5]),
              "Invalid pump timing");
static_assert(PUMP_PIN != STEP_PIN && PUMP_PIN != DIR_PIN && PUMP_PIN != ENABLE_PIN &&
                  PUMP_PIN != BUTTON_PIN,
              "Pump GPIO collision");
static_assert(FULL_STEPS > 0 && MICROSTEPS > 0, "Invalid step scaling");
constexpr double rockStepRate(Preset p) {
  return double(p.speedDegS) * FULL_STEPS * MICROSTEPS / 360.0;
}
constexpr double spinStepRate(Preset p) {
  return double(p.spinRpm) * FULL_STEPS * MICROSTEPS / 60.0;
}
constexpr bool valid(Preset p) {
  return p.amplitudeDeg > 0 && p.speedDegS > 0 && p.accelDegS2 > 0 && p.cycles > 0 &&
         p.spinRpm > 0 && p.spinAccelDegS2 > 0 && p.spinHoldSeconds >= 0 &&
         rockStepRate(p) <= MAX_STEP_RATE &&
         spinStepRate(p) <= MAX_STEP_RATE;
}
static_assert(valid(PRESETS[0]) && valid(PRESETS[1]) && valid(PRESETS[2]) &&
                  valid(PRESETS[3]) && valid(PRESETS[4]) && valid(PRESETS[5]),
              "Invalid preset or requested pulse rate exceeds MAX_STEP_RATE");
} // namespace cfg

static_assert(cfg::PRESET_COUNT == 6, "Update serial/LED controls for preset count changes");

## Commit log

2026-09-26 Add tested ESP8266 separator firmware, button presets and wiring guide
2026-09-26 Add supported brass inlet lid and automatic 12V pump control
    [P08_lid_brass_4mm.step, P08_lid_brass_4mm.stl]
2026-09-26 Archive complete CAD kits and guides; document current build and flow calibration
    [01_motor_base.step, 01_motor_base.stl, 02_bearing_stand.step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]
2026-09-26 Revise P01 for motor harness clearance; reinforce supports and document hardware assumptions
    [P01_base_cable_clearance.step, P01_base_cable_clearance.stl, base_motor_deck_reference.step]
2026-09-26 Replace angled base with straight diagonal posts and document required deck drilling
    [P01_base_cable_clearance.step, P01_base_cable_clearance.stl, P02_drill_template.step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]
2026-09-26 Give corrected vertical-post base a distinct R3 filename and update download links
    [P01_BASE_STRAIGHT_VERTICAL_R3.step, P01_BASE_STRAIGHT_VERTICAL_R3.stl]
2026-09-26 Document shared 12V supply and L7805 regulated NodeMCU power
2026-09-27 Update pump wiring to use available IRF9540N and 2N3904 parts
2026-09-27 Retune loaded-bed agitation with 20x acceleration and bounded spin trials
    Increase rocking amplitude and frequency, keep center-collection spin at 30/45/60 RPM, and defer serial status during motion. Document CAD-derived screening, research limitations and bench acceptance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
2026-09-27 Triple motion speed and acceleration for aggressive bench trial
    Set spin to 90/135/180 RPM, triple rocking ceilings and both acceleration settings, retain stroke angles and dwell times. Update triangular-profile tests, pulse budget and operating limitations. All 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
2026-09-28 Add six motion modes, double agitation and document measured feeding trials
    Preserve modes 1-3 speeds with doubled cycles; add 195/210/225 RPM trials with about ten seconds agitation. Extend button, serial, LED and pump profiles to six modes within the existing pulse budget.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
